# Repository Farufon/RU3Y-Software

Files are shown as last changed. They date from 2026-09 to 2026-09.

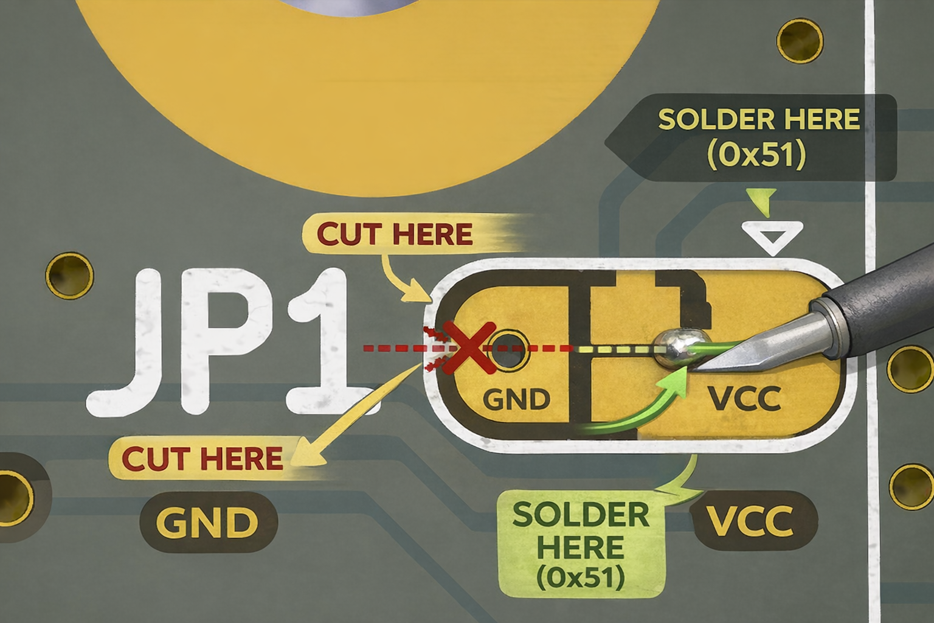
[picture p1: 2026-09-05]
TFRPM01/HOw address the boards.png

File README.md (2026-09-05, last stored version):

# Nacelle Thrust Stand

An axial-post thrust stand for measuring single-nacelle thrust, electrical power, and
ground-effect behaviour on a 914 mm-disc (R = 457 mm) VTOL tilt-rotor nacelle.

Built for a two-nacelle, 15 lb tilt-rotor VTOL. Hover thrust per nacelle is 7.5 lbf.
The deliverable this rig produces is a family of curves: **electrical watts required to
produce 7.5 lbf, as a function of rotor height above ground.**

---

## Start here

- Never used an Arduino? -> `docs/10-arduino-first-time.md`
- Already have the parts and want one page? -> `docs/00-quickstart.md`
- Want to try the software before parts arrive? -> `python3 tools/bench.py --simulate`
- **Before the first spin** -> `docs/09-safety.md`

## What is in this package

```
README.md                          this file

docs/00-quickstart.md              one page, if you already have the parts
docs/01-system-design.md           why this rig, what it measures, what it cannot
docs/02-bill-of-materials.md       parts, quantities, sources, links
docs/03-mechanical-build.md        step-by-step assembly
docs/04-wiring.md                  load cell to HX711 to Arduino, noise control
docs/05-calibration.md             load cell calibration, bidirectional, through-zero check
docs/05a-pitch-and-rpm-calibration.md
                                   servo->pitch and throttle->governed RPM. Do this first.
docs/06-test-protocol.md           the height / RPM / collective grid
docs/07-data-reduction.md          turning the raw log into the delivered curves
docs/08-post-vs-hinge.md           the argument, for the conversation with Vermont
docs/09-safety.md                  read before the first spin
docs/10-arduino-first-time.md      IDE setup, Uno vs Nano, drivers, upload errors
docs/11-load-cell-datasheet.md     ATO cell dimensions, specs, and CAD envelope
docs/wiring-adafruit-hx711.svg     printable wiring diagram - Adafruit 5974 board
docs/wiring-generic-hx711.svg      printable wiring diagram - SparkFun / generic green

firmware/thrust_stand/
    thrust_stand.ino               the sketch. tare, calibrate, stream.

tools/
    bench.py                       laptop app: menu, guided run capture, CSV logging
    reduce.py                      turns the run log into the deliverable table
    requirements.txt               pyserial, and nothing else

data/
    run-log-template.csv           the sheet, if you prefer filling it in by hand
```

## The software, in one paragraph

`thrust_stand.ino` runs on the Arduino and does one job: read the load cell and print
thrust over USB. `bench.py` runs on your laptop, drives the sketch, and walks you through
taring, calibration and a full collective staircase at a governed RPM, writing rows
    into a CSV as you go.
`reduce.py` reads that CSV and interpolates the watts required at 7.5 lbf for every height
you tested. That last table is what you send to Vermont.

## The short version

1. Build the post. Nacelle on top, S-beam load cell directly underneath it, post below
   that, three splayed legs reaching past the disc radius.
2. Wire the cell to an HX711 to an Arduino. Flash the sketch.
3. `pip3 install -r tools/requirements.txt`, then `python3 tools/bench.py`.
4. Calibrate once against known weights.
5. Per height: tare, run the staircase, log each plateau, tare again to verify.
6. `python3 tools/reduce.py data/runs.csv --thrust 7.5 --radius 457`

## Expect

267 to 295 W electrical per nacelle at 7.5 lbf, out of ground effect, depending on
head RPM. Predicted 280 W at 1800 rpm, which matches Austin's measured figure. Hover
collective
about 16 deg at 0.75R at 1600 rpm, falling to 10 deg at 2000. Ground effect will save real
power near the floor, but less than
the textbook thrust benefit suggests, because it reduces induced power only.

## Read first

`docs/09-safety.md`. A 914 mm disc at hover thrust holds enough energy to kill you if a
blade lets go. The blade-failure plane is a **disc, not a cone.** Do not stand in it.

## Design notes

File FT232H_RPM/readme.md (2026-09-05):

##  Pre-Run Hardware Setup

1. **Connections**

   * ESC white signal/tach (AUX) → **1 kΩ resistor** → FT232H **AD0 (D0)**
   * ESC GND → FT232H GND
   * Do **not** connect main PWM throttle line to FT232H (use only AUX/tach output).

2. **Power**

   * Motor/ESC powered by flight battery (watch props/rotor, secure heli or remove blades for bench test).
   * FT232H powered via USB to your Mac/PC.

3. **Safety**

   * Strap heli down or remove main/tail blades during first tests.
   * Wear eye protection — ESCs/motors can surge unexpectedly.

---

##  Software / Command Setup

1. Open Terminal:

   ```bash
   cd ~/Desktop/FT232H_RPM
   ```

2. Run test with **raw motor RPM only**:

   ```bash
   ./rpm_reader_static --poles 8 --ratio 1.0 --index 0 --window 0.05
   ```

   * `--poles 8` = Align 470MX motor (8 poles).
   * `--ratio 1.0` = just motor speed.
   * `--index 0` = first FT232H device.
   * `--window 0.05` = 50 ms averaging window.

3. Run with **gear ratio compensation (rotor head RPM)**:

   ```bash
   ./rpm_reader_static --poles 8 --ratio 8.0 --index 0 --window 0.05
   ```

---

##  Output Verification

Sample output:

```
# t_s, edges, edges_per_s, motor_rpm, rotor_rpm
0.050,120,2400.0,20571,2571
0.100,118,2360.0,20228,2529
```

* `edges` should scale with throttle smoothly.
* `motor_rpm` should be \~20k+ at full throttle (check motor Kv × voltage).
* `rotor_rpm` should be \~2.4–2.6k at 8:1 ratio (matches typical head speeds).

---

##  Sanity Checks

* **Idle / Low Throttle**: rotor\_rpm should rise linearly with throttle.
* **No Throttle**: output should show near zero (a few stray edges OK).
* **Full Throttle**: compare `motor_rpm ≈ Kv × Voltage` and ensure rotor\_rpm ≈ motor\_rpm ÷ ratio.

  * Example: 1800 Kv × 22.2 V ≈ 40k rpm (no load). With 8:1 gear, rotor ≈ 5k rpm max (likely lower under load).

---

 **Tip**: If you see motor RPM correct but rotor RPM looks wrong, double-check `--ratio`.
 If both look wrong, double-check `--poles`.

## LOG TO CSV

Good timing — your program already prints CSV-style lines to `stdout`. You can **tee** or **redirect** them so you get both: live on screen *and* saved to a CSV file.

---

###  Option 1: Tee to File

Keeps live output on screen *and* writes to file:

```bash
./rpm_reader_static --poles 8 --ratio 8.0 --index 0 --window 0.05 | tee rpm_log.csv
```

---

###  Option 2: Redirect to File (no live screen)

Writes only to file (silent on screen):

```bash
./rpm_reader_static --poles 8 --ratio 8.0 --index 0 --window 0.05 > rpm_log.csv
```

---

###  Option 3: Append (multiple runs into one file)

```bash
./rpm_reader_static --poles 8 --ratio 8.0 --index 0 --window 0.05 | tee -a rpm_log.csv
```

---

###  Notes

* The first line of the output (`# t_s, edges, edges_per_s, motor_rpm, rotor_rpm`) will serve as your CSV header.
* If you plan to import into Excel/Numbers, you may want to remove the `#` from the header afterward.

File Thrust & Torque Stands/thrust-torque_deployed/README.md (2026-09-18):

# Nacelle Thrust Stand

An axial-post thrust stand for measuring single-nacelle thrust, electrical power, and
ground-effect behaviour on a 914 mm-disc (R = 457 mm) VTOL tilt-rotor nacelle.

Built for a two-nacelle, 15 lb tilt-rotor VTOL. Hover thrust per nacelle is 7.5 lbf.
The deliverable this rig produces is a family of curves: **electrical watts required to
produce 7.5 lbf, as a function of rotor height above ground.**

Measured operating points from flight test, per nacelle: **hover 1800 rpm at 446 W**,
**cruise after transition 1000 rpm at 185 W**. Rotor disc R = 457 mm. The BEMT model in
this package predicts 274 W for hover and is therefore known to be about 1.6 low; the
torque stand (`docs/14-torque-stand.md`) is how the campaign finds out where that factor
lives.

---

## Start here

- Never used an Arduino? -> `docs/10-arduino-first-time.md`
- Already have the parts and want one page? -> `docs/00-quickstart.md`
- Want to try the software before parts arrive? -> `python3 tools/bench.py --simulate`
- **Python on the Mac: use a venv** -> `docs/15-python-venv.md`. Everything in `tools/`
  assumes you have activated it.
- **Updating, and killing a stale process** -> `INSTALL.md`. Read it before unpacking a new
  zip; Finder will quietly make a `... 2` folder and leave you running old code.
- Not sure which version is on disk? -> `cat VERSION` or `python3 tools/live.py --version`
- **Before the first spin** -> `docs/09-safety.md`

## Arduino and serial: the working configuration

Everything below is proven on the actual hardware. If the board will not flash or
will not talk, this is the section to read. Same text as
`docs/13-arduino-working-config.md`.

Elegoo Nano V3.0 (ATmega328P / CH340) on Intel Mac, macOS 15.7.5.

### The rule

**Use Arduino IDE 1.8.19. Do not use 2.3.10 for uploads.**

2.3.10 ships avrdude 8.0, which cannot write flash to this board.
1.8.19 ships avrdude 6.3, which writes it in 0.23 seconds.

### Settings

| Item | Value |
|---|---|
| IDE | Arduino 1.8.19 (the app named `Arduino`, not `Arduino IDE`) |
| Board | Tools > Board > Arduino AVR Boards > Arduino Nano |
| Processor | Tools > Processor > **ATmega328P** (NOT Old Bootloader) |
| Port | Tools > Port > `/dev/cu.usbserial-XXXX` |
| Verify after upload | Can stay on. Read-back verifies clean on the soldered board. |
| Serial Monitor baud | 115200 for `thrust_stand.ino`, line ending New Line |

Old Bootloader sets 57600 and fails to sync. Plain ATmega328P sets 115200 and works.

### Before every upload

- Quit Arduino IDE 2.3.10 if it is open. Only one program can hold the port.
- Close the Serial Monitor. It holds the port too.
- Nothing connected to D0 (RX) or D1 (TX).
- Re-check Tools > Port after any replug. The name changes.

### Good log looks like

```
avrdude: Version 6.3-20190619
avrdude: Device signature = 0x1e950f (probably m328p)
avrdude: writing flash (924 bytes):
Writing | ############################ | 100% 0.23s
avrdude: 924 bytes of flash written
```

If the version line says `8.0-arduino.1`, you are in the wrong IDE. Stop.

### Known cosmetic errors, safe to ignore

- `the selected serial port does not exist or your board is not connected`
  appended after a successful upload. 1.8.19 concatenating error strings.

### Talking to the board without the Arduino IDE

The firmware does not care what is on the other end of the wire. Any serial
terminal at 115200 baud that sends a newline on Return will work. macOS has
one built in.

#### Find the port

```
ls /dev/cu.usbserial-*
```

If that comes back empty, or you want to see everything:

```
ls /dev/cu.*
```

Ignore `cu.Bluetooth-Incoming-Port` and anything Bluetooth-related. The Nano
is the `cu.usbserial-` entry. If more than one shows up, unplug the Nano,
run it again, plug back in, run it again, and take the one that appeared.

Always use `cu.`, never `tty.`. The `tty.` device blocks waiting for carrier
detect and will hang.

#### Open it

```
screen /dev/cu.usbserial-1480 115200
```

Substitute the actual name from the `ls`. The board resets when the port
opens, so the banner prints a second or so later. Return sends a newline
already, so `t`, `c 3.11`, `d` and `r` all work as typed.

#### Quit

`Control-A` then `Control-\` then `y`. Or `Control-A` then `k` then `y`.

**Quit properly.** Closing the Terminal window leaves `screen` holding the
port and the next thing that tries to open it will fail. If that happens:

```
screen -ls
screen -X -S <the-session-name> quit
```

#### Logging to a file

`screen` scrollback is awkward. To capture a session:

```
screen -L -Logfile ~/thrust-run.txt /dev/cu.usbserial-1480 115200
```

#### Alternatives

- **CoolTerm** (free, GUI): scrollback, logging, timestamps. Easier than
  `screen` for long runs.
- **`tools/live.py`** is the best option in this branch: browser dashboard,
  strip chart, logging, BEMT overlay, and it works from an iPad over the VPN.
  See `docs/12-live-readout.md`.
- **`tools/bench.py`** is the guided grid-capture session. It drives the same port, prompts through the height / RPM /
  collective grid, and writes `data/run-log.csv` directly. No transcribing
  numbers by hand.

### Firmware command reference (`thrust_stand.ino`)

115200 baud, line ending **New Line**. Commands are single letters, case
insensitive, one per line. Anything unrecognised returns `! unknown command`.

| Cmd | Does | Output starts with |
|---|---|---|
| `h` | Help. `?` works too. | `=== Nacelle Thrust Stand ===` |
| `t` | **Tare.** Zeroes to current load, 32 samples. | `# taring, hold still...` |
| `r` | One reading, 8 samples averaged. | `# n,ms,lbf,N,raw` |
| `s` | Toggle streaming. Real rate is ~1.2 Hz on RATE=L. | `# streaming ON` / `OFF` |
| `c <lbf>` | **Calibrate** against a hung known weight, 32 samples. | `# calibrating against ...` |
| `f` | **Flip sign. Required on this rig, every calibration.** | `# sign now -1` |
| `z` | Raw counts, unscaled, 32 samples. Diagnostics. | `# raw counts = ` |
| `d` | Dump settings. | `calFactor (counts/lbf) :` |
| `w` | Force-write settings to EEPROM. | `# settings written` |

#### Reading format

```
# n,ms,lbf,N,raw
4,1106238,3.0906,13.748,444579
```

| Field | Meaning |
|---|---|
| `n` | Sample counter. Resets to 0 when streaming starts. |
| `ms` | `millis()` since boot. Not wall clock. |
| `lbf` | Change from tare, in pounds force. **Meaningless until calibrated.** |
| `N` | Same value in newtons (lbf x 4.4482216). |
| `raw` | Raw HX711 counts, 2 samples. Absolute, not tare-relative. |

`raw` is the field to trust before calibration and the field to watch for
drift after.

#### What survives a power cycle, and what does not

Stored in EEPROM: **calFactor** and **sign**. Both reload at boot.

**NOT stored: the tare offset.** `setup()` re-tares on every boot, 32 samples,
against whatever is sitting on the cell at that instant.

Consequences:

- Do not power up with a load hanging. The board will treat that load as zero.
- The boot banner tells you which state you are in. Either
  `# calibration loaded from EEPROM, calFactor = ...` or
  `# NO CALIBRATION STORED.`
- You still tare with `t` at the start of every run, per the protocol. The
  boot tare is not a substitute, the rig will not have settled yet.

#### Calibration sequence

1. Nacelle mounted, nothing else on it, rig settled. `t`
2. Stack the known weight on the nacelle mount. `c 15.0`
3. `d` and confirm calFactor is no longer `1.0000`.
4. `r` with the weight still on. Should read close to the known value.
5. Swap in a second known weight. `r`. Should read close to that one.
6. Remove all added weight. **`f`.**
7. `d`, confirm `sign : -1`. Lift the mount by hand, `r`, confirm **positive**.

**`f` is not optional on this stand.** The cell sits on top of the post with the
nacelle above it, so dead weight is compression and thrust is tension. `c`
always makes the calibration direction positive, so calibrating with weight
stacked on the mount makes compression positive and thrust would read negative.
Send `f` after every `c`. See `docs/05-calibration.md`.

Guards in the code: `c` with a non-positive number is rejected. `c` with less
than 1000 counts of signal is rejected as "signal too small", which means the
weight is not actually on the cell or the wiring is broken.

#### Per-run procedure

`t` motor off and settled, `s` to stream, run the collective staircase at a
governed RPM, `s` to stop, `t` again and check the zero. **If the second tare
has wandered, discard the run.**

### macOS Terminal command reference

| Command | Does |
|---|---|
| `ls /dev/cu.usbserial-*` | Find the Nano. |
| `ls /dev/cu.*` | List every serial device if the above is empty. |
| `screen /dev/cu.usbserial-1480 115200` | Open the connection. |
| `Control-A` then `Control-\` then `y` | Quit screen properly. |
| `Control-A` then `k` then `y` | Kill the window, same effect. |
| `Control-A` then `Control-A` | Send a literal Control-A to the board. |
| `screen -ls` | List sessions left running. |
| `screen -X -S <name> quit` | Kill an orphaned session holding the port. |
| `screen -L -Logfile ~/run.txt /dev/cu.usbserial-1480 115200` | Open and log to file. |
| `lsof /dev/cu.usbserial-1480` | Find what process is holding the port. |
| `system_profiler SPUSBDataType \| grep -A8 -i ch34` | Confirm the CH340 enumerated at all. |

`screen` does not echo what you type. You will see the board's replies but not
your own keystrokes. That is normal, not a dead connection.

### Cable length

USB 2.0 passive cable tops out at about 5 m (16 ft). Beyond that, expect
intermittent dropouts. For a long run to the stand use an **active** USB
extension (repeater chip in the connector) or a **mains-powered** hub at the
midpoint. A bus-powered hub on a long cable is worse than no hub.

A hub does not change the device identity. The CH340 keeps its vendor and
product ID and still enumerates as `cu.usbserial-`. Only the number changes,
same as it does on any replug.

Lengthen the USB, never the load cell leads. Those carry millivolt analog
signal and will pick up ESC and motor noise. Nano and HX711 stay at the stand.

### Do not

- Do not install the WCH CH34x driver. Current setup works. Leave it alone.
- Do not buy a USBasp. Bootloader is fine, signature reads clean.
- Do not use Old Bootloader.
- Do not use `/dev/tty.usbserial-*`. Use `/dev/cu.usbserial-*`.

---

## What is in this package

```
README.md                          this file

docs/00-quickstart.md              one page, if you already have the parts
docs/01-system-design.md           why this rig, what it measures, what it cannot
docs/02-bill-of-materials.md       parts, quantities, sources, links
docs/03-mechanical-build.md        step-by-step assembly
docs/04-wiring.md                  load cell to HX711 to Arduino, noise control
docs/05-calibration.md             load cell calibration, bidirectional, through-zero check
docs/05a-pitch-and-rpm-calibration.md
                                   servo->pitch and throttle->governed RPM. Do this first.
docs/06-test-protocol.md           the height / RPM / collective grid
docs/07-data-reduction.md          turning the raw log into the delivered curves
docs/08-post-vs-hinge.md           the argument, for the conversation with Vermont
docs/09-safety.md                  read before the first spin
docs/10-arduino-first-time.md      IDE setup, Uno vs Nano, upload errors, first bring-up
docs/11-load-cell-datasheet.md     ATO cell dimensions, specs, and CAD envelope
docs/12-live-readout.md            tools/live.py: browser dashboard, logging, power overlay
docs/13-arduino-working-config.md  THE PROVEN SETTINGS. Read this one first if stuck.
docs/14-torque-stand.md            the separate torque rig: second board, second cell
docs/15-python-venv.md             Python on the Mac. Do this before any tools/ command.
docs/wiring-adafruit-hx711.svg     printable wiring diagram - Adafruit 5974 board
docs/wiring-generic-hx711.svg      printable wiring diagram - SparkFun / generic green
docs/wiring-torque-stand.svg       torque stand wiring - second Nano, second HX711, 5 kg cell
docs/torque-stand-elevation.svg    torque stand side elevation with callouts
docs/torque-stand-plan.svg         torque stand plan view: arm, cell, anchor, calibration notes

firmware/thrust_stand/
    thrust_stand.ino               the sketch. tare, calibrate, stream.

firmware/torque_stand/
    torque_stand.ino               second board. reports torque in N.m. See docs/14.

cad/
    torque_cradle.py               Fusion script, builds the torque cradle parts

INSTALL.md                         unpacking, updating, killing stale processes. READ FIRST.
VERSION                            date-stamped build id; live.py prints it at startup

tools/
    stop.sh                        kills stale live.py/bench.py, reports port holders
    live.py                        browser dashboard: live readout, strip chart,
                                   logging, BEMT power overlay. See docs/12.
    bemt_curves_v49.json           predicted thrust/power curves, R = 457 mm
    bench.py                       laptop app: menu, guided run capture, CSV logging
    reduce.py                      turns the run log into the deliverable table
    requirements.txt               pyserial, and nothing else. Install into a venv,
                                   never the system Python. See docs/15.

data/
    run-log-template.csv           the sheet, if you prefer filling it in by hand
```

## The software, in one paragraph

`thrust_stand.ino` runs on the Arduino and does one job: read the load cell and print
thrust over USB. `bench.py` runs on your laptop, drives the sketch, and walks you through
taring, calibration and a full collective staircase at a governed RPM, writing rows
    into a CSV as you go.
`reduce.py` reads that CSV and interpolates the watts required at 7.5 lbf for every height
you tested. That last table is what you send to Vermont.

## The short version

1. Build the post. Nacelle **bolted** on top, S-beam load cell **bolted** directly
   underneath it, post below that, three splayed legs reaching past the disc radius.
   Both studs carry load: dead weight presses the cell in compression, thrust pulls it in
   tension, and it reads continuously through zero between them.
2. Wire the cell to an HX711 to an Arduino. Flash the sketch (IDE 1.8.19, plain ATmega328P).
3. Set up the Python environment once, per `docs/15-python-venv.md`:

```
/Library/Frameworks/Python.framework/Versions/3.12/bin/python3 -m venv ~/venvs/forcerigs
xattr -r -d com.apple.quarantine ~/venvs/forcerigs/
source ~/venvs/forcerigs/bin/activate
pip install --upgrade pip
pip3 install pyserial
```

Every new Terminal window needs the `source` line again. The prompt shows
`(forcerigs)` when it is live. Full detail, including how to start over, is in
`docs/15-python-venv.md`.

   Then `cd tools && python3 bench.py`.
4. Calibrate once, in compression, with weight stacked on the nacelle mount. **Then send
   `f`.** It is required on this geometry, and any recalibration undoes it, so `f` goes last
   every time. Confirm `sign : -1` and that lifting the mount reads positive.
5. Per height: tare with the nacelle on and the motor off, run the staircase, log each
   plateau, tare again to verify.
6. `python3 tools/reduce.py data/runs.csv --thrust 7.5 --radius 457`

## Expect

The BEMT predicts 267 to 295 W electrical per nacelle at 7.5 lbf out of ground effect,
depending on head RPM, with hover collective about 16 deg at 0.75R at 1600 rpm falling to
10 deg at 2000.

**Flight test puts hover at 446 W per nacelle at 1800 rpm**, against a prediction of
274 W. Your 1800 rpm OGE point must land near 446 before anything else means anything. That is a factor of 1.63, and it implies a figure of merit of 0.43 where the model
claims 0.70. Either the rotor is far worse than modelled, or the drivetrain is running at
about 48% rather than the assumed 79%. Electrical watts alone cannot separate those two.
The torque stand can, and that is what `docs/14-torque-stand.md` is for.

The `live.py` power chart marks that point with an amber diamond. Expect your captured
points to land near it and well above the BEMT curves. The gap to the curves is the
model's problem; the gap to the diamond is yours.

His cruise target after transition is 1000 rpm at 185 W per nacelle. That point is not
reproducible on a static stand; see doc 14.

Ground effect will save real power near the floor, but less than the textbook thrust
benefit suggests, because it reduces induced power only.

## Read first

`docs/09-safety.md`. A 914 mm disc at hover thrust holds enough energy to kill you if a
blade lets go. The blade-failure plane is a **disc, not a cone.** Do not stand in it.

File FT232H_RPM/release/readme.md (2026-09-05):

Great—thanks for the exact filenames. You have:

* `build/libftd2xx.1.4.30.dylib` (dynamic library)
* `build/libftd2xx.a` (static library)
* `ftd2xx.h`, `WinTypes.h`
* plus some subfolders

Below is a **from-scratch, copy-pasteable** setup that works with *your* files and avoids guessing.

---

# 1) Make a clean project folder

```bash
mkdir -p ~/Desktop/FT232H_RPM
cd ~/Desktop/FT232H_RPM
```

Copy the **headers** and the **.dylib** in:

```bash
# adjust the source path below to wherever your "release" folder actually is:
cp /Users/jon/Desktop/FT232H_RPM/release/ftd2xx.h .
cp /Users/jon/Desktop/FT232H_RPM/release/WinTypes.h .
cp /Users/jon/Desktop/FT232H_RPM/release/build/libftd2xx.1.4.30.dylib .
```

(Optional but convenient) add a symlink with a generic name:

```bash
ln -sf libftd2xx.1.4.30.dylib libftd2xx.dylib
```

You should now have:

```
~/Desktop/FT232H_RPM/
  ftd2xx.h
  WinTypes.h
  libftd2xx.1.4.30.dylib
  libftd2xx.dylib  -> libftd2xx.1.4.30.dylib (symlink)
```

---

# 2) Check architecture (VERY IMPORTANT on Apple Silicon)

Your Mac is **arm64**. Make sure the library matches:

```bash
lipo -info libftd2xx.1.4.30.dylib
```

* If it says **arm64** (or **arm64 x86\_64**), you’re good.
* If it says **x86\_64 only**, you have an Intel-only build. Either:

  * grab an **arm64** macOS D2XX build, **or**
  * run under Rosetta (see “Plan B” at the end).

---

# 3) Create the app source file

Create `rpm_reader.c` here with this content (same as earlier, kept local-include):

```c
// rpm_reader.c — FT232H + D2XX RPM reader for Castle ESC AUX "RPM OUT"
// Wiring: ESC white AUX -> 1k -> FT232H AD0 (D0); ESC GND -> FT232H GND
// Build:  clang -O2 -Wall rpm_reader.c -o rpm_reader -I. -L. -l:libftd2xx.1.4.30.dylib -Wl,-rpath,@executable_path

#include <stdio.h>
#include <stdlib.h>
#include <stdint.h>
#include <string.h>
#include <time.h>
#ifdef __APPLE__
#include <mach/mach_time.h>
#endif

#include "ftd2xx.h"   // in current directory

static int    motor_poles = 14;     // total magnets, e.g. 14 -> 7 pole-pairs
static double gear_ratio  = 1.0;    // motor:rotor (10.0 for 10:1)
static int    dev_index   = 0;      // FTDI device index to open
static double window_s    = 0.05;   // seconds per RPM sample (50 ms)

static double now_s(void) {
#ifdef __APPLE__
    static mach_timebase_info_data_t tb;
    static uint64_t start = 0;
    if (!tb.denom) mach_timebase_info(&tb);
    if (!start) start = mach_absolute_time();
    uint64_t t = mach_absolute_time() - start;
    double ns = (double)t * (double)tb.numer / (double)tb.denom;
    return ns * 1e-9;
#else
    struct timespec ts; clock_gettime(CLOCK_MONOTONIC, &ts);
    return (double)ts.tv_sec + (double)ts.tv_nsec * 1e-9;
#endif
}

static void die(const char *msg, FT_STATUS st) {
    fprintf(stderr, "%s (FT_STATUS=%ld)\n", msg, (long)st);
    exit(1);
}

static void usage(const char *prog) {
    fprintf(stderr,
        "Usage: %s [--poles N] [--ratio R] [--index I] [--window S]\n"
        "  --poles   Total motor poles (default 14)\n"
        "  --ratio   Gear ratio motor:rotor (default 1.0)\n"
        "  --index   FTDI device index to open (default 0)\n"
        "  --window  Seconds per RPM sample window (default 0.05)\n",
        prog);
}

int main(int argc, char **argv) {
    for (int i=1; i<argc; ++i) {
        if (!strcmp(argv[i], "--poles") && i+1<argc)      motor_poles = atoi(argv[++i]);
        else if (!strcmp(argv[i], "--ratio") && i+1<argc) gear_ratio  = atof(argv[++i]);
        else if (!strcmp(argv[i], "--index") && i+1<argc) dev_index   = atoi(argv[++i]);
        else if (!strcmp(argv[i], "--window") && i+1<argc)window_s    = atof(argv[++i]);
        else { usage(argv[0]); return 1; }
    }
    if (motor_poles < 2) motor_poles = 2;
    int pole_pairs = motor_poles / 2;
    if (pole_pairs < 1) pole_pairs = 1;
    if (gear_ratio <= 0.0) gear_ratio = 1.0;
    if (window_s < 0.01) window_s = 0.01;

    FT_STATUS st;
    FT_HANDLE ft;

    st = FT_Open(dev_index, &ft);
    if (st != FT_OK) die("FT_Open failed", st);

    FT_SetLatencyTimer(ft, 2); // ms

    UCHAR mask = 0x00; // all inputs
    UCHAR mode = 0x01; // async bit-bang
    st = FT_SetBitMode(ft, mask, mode);
    if (st != FT_OK) die("FT_SetBitMode failed", st);

    printf("# t_s, edges, edges_per_s, motor_rpm, rotor_rpm\n");
    double t0 = now_s();
    double block_start = t0;

    UCHAR prev = 0, cur = 0;
    st = FT_GetBitMode(ft, &prev);
    if (st != FT_OK) die("FT_GetBitMode (init) failed", st);
    prev &= 0x01;

    for (;;) {
        unsigned edges = 0;
        double deadline = block_start + window_s;

        while (now_s() < deadline) {
            st = FT_GetBitMode(ft, &cur);
            if (st != FT_OK) die("FT_GetBitMode failed", st);
            UCHAR bit = cur & 0x01;  // AD0 is LSB
            if (prev == 0 && bit == 1) edges++; // rising edge
            prev = bit;
        }

        double window_actual = now_s() - block_start;
        block_start = now_s();

        double eps = edges / (window_actual > 0 ? window_actual : window_s);
        double motor_rpm = (eps * 60.0) / pole_pairs;
        double rotor_rpm = motor_rpm / gear_ratio;

        printf("%.3f,%u,%.1f,%.0f,%.0f\n",
               now_s()-t0, edges, eps, motor_rpm, rotor_rpm);
        fflush(stdout);
    }

    FT_Close(ft);
    return 0;
}
```

---

# 4) Build (links to your exact dylib name)

```bash
cd ~/Desktop/FT232H_RPM
clang -O2 -Wall rpm_reader.c -o rpm_reader \
  -I. -L. \
  -l:libftd2xx.1.4.30.dylib \
  -Wl,-rpath,@executable_path
```

**Why this works:**

* `-I.` and `-L.`: use headers and libs from the current folder
* `-l:…` links **that exact filename** (no need to rename)
* `-Wl,-rpath,@executable_path` lets the app find the dylib **next to the binary** at runtime

> If Gatekeeper blocks the library the first time, clear quarantine once:
>
> ```bash
> xattr -dr com.apple.quarantine libftd2xx.1.4.30.dylib rpm_reader
> ```

---

# 5) Wire & run

**Wiring recap**

* ESC **white AUX** → **1 kΩ** → FT232H **AD0 (D0)**
* ESC **GND** → FT232H **GND**
* Don’t connect the ESC +5 V to FT232H VCC (FT232H is USB powered)

**Run**

```bash
./rpm_reader --poles 14 --ratio 1.0 --index 0 --window 0.05
```

You should see CSV rows like:

```
# t_s, edges, edges_per_s, motor_rpm, rotor_rpm
0.051,125,2482.5,21236,21236
0.102,121,2410.3,20659,20659
```

Tweak flags as needed:

* `--poles N` → total motor poles (14 ⇒ 7 pole-pairs)
* `--ratio R` → motor\:rotor (10.0 for 10:1)
* `--window S` → 0.02–0.10 typical
* `--index I` → if multiple FTDI devices connected

---

## If you get errors

* **`ld: library not found for -l:libftd2xx.1.4.30.dylib`**
  Ensure the file is in the same directory as you’re compiling from and you included `-L.`

* **`dyld: Library not loaded: libftd2xx.1.4.30.dylib`**
  Ensure `-Wl,-rpath,@executable_path` is in the compile line, or run once with:

  ```bash
  export DYLD_LIBRARY_PATH=.
  ./rpm_reader ...
  ```

* **`image not found` or Apple security prompt**
  Clear quarantine:

  ```bash
  xattr -dr com.apple.quarantine libftd2xx.1.4.30.dylib rpm_reader
  ```

  If it still complains, open **System Settings → Privacy & Security** and click **Allow Anyway** for the blocked item, then run again.

* **Architecture mismatch**
  If `lipo -info` showed **x86\_64 only** and your Mac is arm64:

  * Best: obtain an **arm64** build of `libftd2xx.1.4.30.dylib`.
  * Plan B (Rosetta): build and run everything as x86\_64:

    ```bash
    # compile for x86_64
    arch -x86_64 clang -O2 -Wall rpm_reader.c -o rpm_reader_x86 \
      -I. -L. -l:libftd2xx.1.4.30.dylib -Wl,-rpath,@executable_path
    # run under Rosetta
    arch -x86_64 ./rpm_reader_x86 --poles 14 --ratio 1.0
    ```

* **Always zero edges**
  Check wiring (AD0/D0 is bit 0), **common ground**, and confirm **AUX = RPM Out** in Castle Link.

---

## Optional: static link (no .dylib at runtime)

If you want to avoid the dynamic library entirely and the static **`.a`** matches your architecture, you can link it directly:

```bash
clang -O2 -Wall rpm_reader.c -o rpm_reader_static \
  -I. /path/to/release/build/libftd2xx.a
```

If that works, you can run `./rpm_reader_static` without shipping a `.dylib`.

---

That’s the whole path with your specific `libftd2xx.1.4.30.dylib`. If you hit a specific compiler or runtime message, paste it verbatim and I’ll adjust the exact flags fast.

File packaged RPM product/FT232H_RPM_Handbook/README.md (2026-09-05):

# FT232H → Castle ESC RPM Kit (macOS, No Python)

This is a distributable handbook + project that measures **real‑time RPM** from a Castle ESC’s **AUX (white) RPM OUT** using an **FT232H** and the **FTDI D2XX** API—compiled as a **static binary** for a zero‑dependency run.

## Contents

```
FT232H_RPM_Handbook/
├─ src/
│  ├─ rpm_reader.c          # core reader (CSV to stdout)
│  └─ list_ftdi.c           # helper: list FTDI devices / serials
├─ docs/
│  ├─ C - FT232H TUTORIAL.md                 # full setup & wiring
│  ├─ QUICKSTART.md                          # concise run + logging
│  └─ RUNNING TWO RPM FT232Hs in REAL TIME.md# dual boards, AppleScript/tmux tips
├─ vendor/ftdi/
│  ├─ ftd2xx.h, WinTypes.h                   # FTDI headers
│  ├─ libftd2xx.a                            # static lib (preferred)
│  ├─ ftd2xx.cfg                             # optional config (advanced)
│  ├─ release-notes.txt                      # FTDI D2XX changelog
│  └─ ReadMe.rtf                             # FTDI install notes
├─ scripts/
│  ├─ build_static.sh                        # one-click static build
│  └─ run_dual.scpt                          # opens two Terminal windows
└─ BUILD.md                                   # build & run instructions
```

## Quick Start

1. **Props off.** Wire AUX (white) → 1 kΩ → FT232H **AD0(D0)** and **GND → GND**.  
2. Ensure Castle **AUX = RPM OUT** (Castle Link).  
3. Build static binary:

   ```bash
   ./scripts/build_static.sh
   ```

4. Run (single board):

   ```bash
   ./rpm_reader_static --poles 8 --ratio 8.0 --index 0 --window 0.05
   ```

   Log to CSV while keeping live output:

   ```bash
   ./rpm_reader_static --poles 8 --ratio 8.0 --index 0 --window 0.05 | tee rpm_log.csv
   ```

5. Run **two** FT232H boards (two windows):

   ```bash
   osascript scripts/run_dual.scpt
   ```

## Notes

- `motor_rpm` is derived from commutation edges and **pole‑pairs**.  
- `rotor_rpm = motor_rpm / gear_ratio`.  
- If you swap USB ports and device indices change, compile and use `src/list_ftdi.c` to enumerate serials and extend the reader to open by serial (optional).

---

**License & Attribution**  
FTDI headers/libraries are © FTDI and redistributed under their terms. See `vendor/ftdi/release-notes.txt` and the header notices. Your source files are yours—add your preferred license as needed.

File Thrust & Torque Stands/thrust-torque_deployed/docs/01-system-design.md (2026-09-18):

# 01 - System Design

## The question this rig answers

Vermont has flying aircraft. The question is not "will it lift." The question is what the
power draw looks like through the takeoff transition, from sitting on the ground up to
free-air hover, where ground effect is real and where the pack sees its hardest moment.

So the measured output is:

> **Electrical watts to produce 7.5 lbf, as a function of rotor height above ground,
> minimised over the available combinations of head RPM and collective pitch.**

Not thrust at full throttle. Not thrust at one height. A curve of watts against height at
constant thrust. That is what sizes his pack and tells him what climb-out costs.

## Rotor definition - settled

This was ambiguous for a while and is now closed. From Austin's design source, 4 September:

```
tip_radius          = 457.0    // tip radius from hub centerline, mm
CENTER_HUB_to_FIBER =  31.0    // hub centreline to base of the grip
```

**457 mm is the rotor radius, measured from the hub centreline to the blade tip.** The blade
itself is 426 mm of physical length, running from r = 31 mm out to r = 457 mm.

The earlier `BLADETEST.step` file, 499.5 mm root face to tip, is **superseded**. Austin
identified it as one of an earlier family built while he was exploring longer radii. Do not
size anything from it. The current blade is the **SOLID CORE V49** pair, supplied as
`PROP_CORE_CW` and `PROP_CORE_CCW`.

### Measured blade geometry, V49 core

Taken directly off the supplied STL meshes rather than from the design intent.

| Quantity | Value |
|---|---|
| Rotor radius R | 457.0 mm |
| Blade physical length | 426.0 mm (r = 31 to 457) |
| Blades per rotor | 2 |
| Max chord | 33.84 mm at r/R = 0.75 |
| Reference chord (Austin's source) | 35.0 mm |
| Built-in twist, r/R 0.22 to tip | 33.3 degrees, washout |
| Thickness ratio | 17.7% at r/R 0.22, tapering to 12.2% at the tip |
| Geometric solidity | 0.0286 |
| Thrust-weighted solidity | 0.0388 |
| Thrust-weighted equivalent chord | 27.8 mm |
| Disc area | 0.656 m^2 |
| Disc loading at 7.5 lbf | 50.8 N/m^2 |
| Root airfoil | GOE 601 |
| Tip airfoil | DEFIANT CANARD |

The CW and CCW files were checked against each other and are an **exact mirror pair**, zero
deviation after reflection. The handed set is correct; you are not about to build two rotors
of the same hand.

Note these are the **printed cores**. The finished blade carries carbon over them, two to
five plies per side depending on span station, which adds a little thickness and a little
chord. The aerodynamic effect is small and is inside the uncertainty of the drag polar.

## Measured operating points

These come from Austin's per-blade and flying tests and are the numbers the rig has to
reproduce. Both are **per nacelle**. Rotor disc unchanged, R = 457 mm.

| Condition | Head RPM | Electrical W | A at 21 V | Shaft W at η 0.79 | Torque |
|---|---|---|---|---|---|
| **Hover** | **1800** | **446** | 21.2 | 352 | 1.87 N·m |
| **Cruise**, after transition | **1000** | **185** | 8.8 | 146 | 1.39 N·m |

The shaft column assumes the nominal 0.95 x 0.83 drivetrain until the torque stand
replaces that assumption with a measurement. The torque column is what the torque stand
should read at each condition if the assumption holds.

Aircraft totals, two nacelles: 892 W in hover, 370 W in cruise.

## Predicted power at hover, BEMT

Blade-element momentum analysis against the measured V49 geometry, tip-loss corrected,
trimmed to 7.5 lbf per nacelle, with 0.95 gearbox and 0.83 combined motor and ESC
efficiency. **This is the model. It is now known to be wrong by a factor of about 1.6 at
the hover point, and the interesting question is where that factor lives.**

| Head RPM | Tip speed m/s | Collective at 0.75R | Shaft W | FM | Electrical W | A at 21 V | Max thrust lbf | Margin |
|---|---|---|---|---|---|---|---|---|
| 1500 | 71.8 | 20.5 | 228 | 0.666 | 290 | 13.8 | 7.5 | **1.00** |
| 1600 | 76.6 | 16.1 | 217 | 0.699 | 276 | 13.1 | 8.6 | 1.14 |
| 1700 | 81.4 | 14.1 | 218 | 0.698 | 276 | 13.2 | 9.7 | 1.29 |
| **1800** | 86.1 | 12.6 | 221 | 0.688 | **280** | 13.3 | 10.8 | 1.44 |
| 1900 | 90.9 | 11.3 | 226 | 0.673 | 286 | 13.6 | 12.1 | 1.61 |
| 2000 | 95.7 | 10.3 | 232 | 0.655 | 294 | 14.0 | 13.4 | 1.78 |

At 1400 rpm this rotor **cannot reach 7.5 lbf at all** before the blade stalls.

Two things to take from this table, and one retraction.

**The model is out by about 1.6 at hover.** It predicts 274 to 280 W at 1800 rpm depending
on the drag polar (the table above is one run, the curve file in `tools/` is another);
Austin measures 446 W.
At the assumed drivetrain efficiency that is 352 W of shaft power for a job whose ideal
induced power is 152 W, a figure of merit of 0.43 where the model claims 0.69. Two
explanations fit and are not distinguishable from electrical watts alone:

- the rotor is far worse than modelled and really does take about 352 W of shaft power, or
- the rotor is close to the model at about 216 W and the drivetrain is delivering roughly
  48 percent rather than 79.

Any mix of the two is also possible. Separating them is exactly what `docs/14-torque-stand.md`
exists for, and it decides whether the fix is in the blades or in the motor and ESC. Until
that measurement exists, treat every BEMT number in this package as a shape, not a value.

**Power is nearly flat with RPM in the model; thrust margin is not.** Between 1600 and 2000
rpm predicted hover power varies by under 7 percent, but maximum thrust nearly doubles, from
8.6 to 13.4 lbf. RPM on this rotor buys control authority far more than it costs
efficiency. That conclusion is about the shape of the curves and should survive the 1.6
factor; the sweep will confirm or kill it.

> **Retraction, September 2026.** An earlier version of this document said the 280 W
> figure was **confirmed**, because the model landed on Austin's then-measured 280 W at
> 1800 rpm. Flying tests now put hover at 446 W. The agreement was a coincidence and I
> over-read it. What changed between the 280 W reading and the 446 W reading is a question
> for Austin, but the 446 W figure is the one from flight and it stands.

> **Retraction, earlier.** Working from the superseded 499.5 mm blade with its 46.3 degree
> twist, I recommended exploring **lower** head RPM on the grounds that 1600 was above the
> figure-of-merit optimum. That does not survive the corrected geometry. On the V49 the FM
> peak sits near 1600 to 1700 rpm and is very flat, while thrust margin falls away steeply
> below it. The sweep in doc 06 runs upward from 1600.

### The governor question is closed: 1800

Earlier in this project the nacelle RPM was quoted as 1600 and Austin's design source said
1800. Flying tests settle it: **hover is at 1800 rpm.** The 1600 row in the table above
is still worth measuring, because it shows how much margin the aircraft would give up by
slowing down, but it is not the operating point.

### Cruise is not a static condition

After transition the nacelles tilt and the rotor works as a propeller with axial inflow
from airspeed. At 1000 rpm and 185 W it is absorbing 1.39 N·m. Statically at 1000 rpm the
model tops out at 3.34 lbf, 88 W and 0.66 N·m at 21.9 degrees collective, so a static
stand runs out of collective at about half the cruise torque. The thrust stand cannot
reproduce cruise, and the deliverable does not ask it to. What transfers from cruise is
the drivetrain efficiency at 1000 rpm and 1.39 N·m, which the torque stand can get by
loading the motor in deep stall if the head has the pitch range. Doc 14 covers it.

## Ground effect, and why the height ladder matters

The classic Cheeseman-Bennett relation gives the thrust benefit at constant power:

```
T_IGE / T_OGE  =  1 / (1 - (R / 4z)^2)
```

where `z` is rotor height above ground and `R` is rotor radius. At R = 457 mm:

| z/R | z (mm) | z (in) | T_IGE / T_OGE |
|---|---|---|---|
| 0.5 | 229 | 9.0 | 1.333 |
| 0.75 | 343 | 13.5 | 1.125 |
| 1.0 | 457 | 18.0 | 1.067 |
| 1.25 | 571 | 22.5 | 1.042 |
| 1.5 | 686 | 27.0 | 1.029 |
| 2.0 | 914 | 36.0 | 1.016 |

**The model breaks down below z/R = 0.5.** At z/R = 0.33 the formula returns a 2.35x thrust
benefit, which is physically nonsense. Below half a radius, measure and do not predict. This
is one of the reasons the rig exists.

Two things follow:

1. Ground effect is essentially gone by z/R = 2. The residual benefit there is 1.6 percent,
   which is smaller than your measurement scatter. **The ladder therefore stops at z/R = 2**
   rather than running out to 3. At R = 457 that caps the top of the sweep at 914 mm, which
   is what makes indoor testing practical.
2. **Read the data at constant thrust, not constant power.** The table above is a thrust
   benefit. Vermont does not care that thrust rises near the ground. He cares that at his
   hover thrust the wattage is lower near the ground and climbs as the aircraft leaves it.

A caution on interpretation: ground effect reduces **induced** power only. Profile power
and drivetrain loss are unchanged by height. Ideal induced power at 7.5 lbf on this disc
is 152 W. The model put shaft power at about 220 W, making induced power **79 percent** of
the total; at the measured 446 W electrical and roughly 352 W shaft, induced power is only
about **43 percent** of the total, and the rest is profile drag, drivetrain loss, or both.
So a 7 percent thrust benefit near the floor buys well under 7 percent off the watts, and
less than the model would have led you to expect. Ground effect will still show clearly in
the data, but the low rungs of the ladder will save fewer watts than the textbook table
implies. Measure it rather than scaling it.

## Why the rotor is now governed, and what that does to the test

The head is **variable pitch with a governed RPM**. The ESC reads RPM and Austin's software
holds it at a setpoint. This changes the shape of the test fundamentally:

> **Throttle percentage is an RPM setpoint, not a power setting.** Thrust comes from
> collective pitch, not from throttle.

The original throttle staircase in this package measured nothing useful under a governor;
walking throttle up simply commanded a series of RPMs while the governor absorbed the
difference. The inner loop is now a **two-dimensional grid of head RPM against collective
pitch**, and the deliverable at each height is the (RPM, pitch) pair that produces 7.5 lbf
for the fewest watts. See doc 06.

## Build the rig parametric

Austin has said plainly that the radius **will increase later**, and that he will want
deeper gear ratios as props grow. Two consequences for the build:

- Splay the legs so the feet clear a **700 mm radius** rotor, not a 457 mm one. Recutting
  legs later is annoying; cutting them long now is free.
- Express the height ladder as **z/R with a fill-in millimetre column**, not as hard-coded
  millimetres. `reduce.py` takes `--radius` for exactly this reason.
- Plan floor-to-ceiling clearance for **4.2 m** so the same room still works at a larger
  radius. At R = 457 you need far less, but you do not want to move rooms.

Post sections get recut per prop. That is expected and cheap.

## Why an axial post

The nacelle mounts on top of a single vertical post that runs down the thrust axis,
directly beneath the hub. The prop sits above the motor in hover attitude, so the entire
volume below the nacelle is clear and the post never approaches the blades.

- **No lever arm.** Load is purely axial. There is no arm ratio to measure and therefore no
  arm ratio to get wrong.
- **Height is an independent variable.** You pin it and walk away. Nothing swings.
- **Almost nothing in the flow is measured.** The load cell sits directly under the nacelle.
  It only registers what is between it and the nacelle. The post, legs and base are below
  the cell and outside the load path, so their drag does not appear in the reading.

For scale on that last point: induced velocity at the disc is about 4.5 m/s at hover, rising
to roughly 9 m/s in the contracted wake. A 25 mm tube running two feet down through that
would carry roughly a tenth of a pound of download. Below the cell, it is exactly zero.

## The load reversal - read this before you build

The nacelle is about 1200 g. With the yoke and adapter plate the dead weight above the cell
is roughly **4.5 to 5 lb, acting downward in compression**. Thrust acts upward. So as you
walk the collective up, the cell passes through **zero net load at about 4.8 lbf of thrust**,
which is 64 percent of hover and sits in the middle of every sweep you will run.

This is not a nuisance detail. It has three consequences that are handled elsewhere in the
package and are listed here so the reason is in one place:

1. Any clearance in the threaded joints shows up as a **discontinuity right in the middle of
   the data**, and it looks convincingly like real aerodynamics. This is why the jam-nut
   preload and the no-rod-ends rule in doc 03 are load-bearing requirements rather than good
   practice.
2. The cell must be calibrated in **both directions**, and continuity through zero verified.
   See doc 05.
3. The hold-down must resist roughly **8 lbf of uplift** at peak thrust.

An optional 10 lb ballast above the cell keeps it in compression throughout, but it lowers
the fixture's resonant frequency toward 2/rev, which at 1800 rpm is 60 Hz. Try preload
first.

## What this rig cannot tell you

State these plainly in the delivery note.

1. **Fountain flow.** Two rotors on a wing, in ground effect, throw wake inward and upward
   against the underside of the wing. That download exists on the real aircraft and cannot
   appear in single-nacelle data.
2. **Rotor-to-rotor interference.** Same reason.
3. **Wing download in free-air hover.** The wing sits in the wake. Not reproduced here.
4. **Trim and control margin.** This measures thrust available, not authority remaining.

What you are delivering is **isolated per-nacelle performance, in and out of ground effect,
as a function of height, at the best available RPM and pitch combination.** Airframe
integration is Vermont's problem, and saying so up front protects both of you.

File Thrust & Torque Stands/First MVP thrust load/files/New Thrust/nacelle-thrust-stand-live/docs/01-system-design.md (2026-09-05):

# 01 - System Design

## The question this rig answers

Vermont has flying aircraft. The question is not "will it lift." The question is what the
power draw looks like through the takeoff transition, from sitting on the ground up to
free-air hover, where ground effect is real and where the pack sees its hardest moment.

So the measured output is:

> **Electrical watts to produce 7.5 lbf, as a function of rotor height above ground,
> minimised over the available combinations of head RPM and collective pitch.**

Not thrust at full throttle. Not thrust at one height. A curve of watts against height at
constant thrust. That is what sizes his pack and tells him what climb-out costs.

## Rotor definition - settled

This was ambiguous for a while and is now closed. From Austin's design source, 4 September:

```
tip_radius          = 457.0    // tip radius from hub centerline, mm
CENTER_HUB_to_FIBER =  31.0    // hub centreline to base of the grip
```

**457 mm is the rotor radius, measured from the hub centreline to the blade tip.** The blade
itself is 426 mm of physical length, running from r = 31 mm out to r = 457 mm.

The earlier `BLADETEST.step` file, 499.5 mm root face to tip, is **superseded**. Austin
identified it as one of an earlier family built while he was exploring longer radii. Do not
size anything from it. The current blade is the **SOLID CORE V49** pair, supplied as
`PROP_CORE_CW` and `PROP_CORE_CCW`.

### Measured blade geometry, V49 core

Taken directly off the supplied STL meshes rather than from the design intent.

| Quantity | Value |
|---|---|
| Rotor radius R | 457.0 mm |
| Blade physical length | 426.0 mm (r = 31 to 457) |
| Blades per rotor | 2 |
| Max chord | 33.84 mm at r/R = 0.75 |
| Reference chord (Austin's source) | 35.0 mm |
| Built-in twist, r/R 0.22 to tip | 33.3 degrees, washout |
| Thickness ratio | 17.7% at r/R 0.22, tapering to 12.2% at the tip |
| Geometric solidity | 0.0286 |
| Thrust-weighted solidity | 0.0388 |
| Thrust-weighted equivalent chord | 27.8 mm |
| Disc area | 0.656 m^2 |
| Disc loading at 7.5 lbf | 50.8 N/m^2 |
| Root airfoil | GOE 601 |
| Tip airfoil | DEFIANT CANARD |

The CW and CCW files were checked against each other and are an **exact mirror pair**, zero
deviation after reflection. The handed set is correct; you are not about to build two rotors
of the same hand.

Note these are the **printed cores**. The finished blade carries carbon over them, two to
five plies per side depending on span station, which adds a little thickness and a little
chord. The aerodynamic effect is small and is inside the uncertainty of the drag polar.

## Expected power at hover

Blade-element momentum analysis against the measured V49 geometry, tip-loss corrected,
trimmed to 7.5 lbf per nacelle, with 0.95 gearbox and 0.83 combined motor and ESC
efficiency.

| Head RPM | Tip speed m/s | Collective at 0.75R | Shaft W | FM | Electrical W | A at 21 V | Max thrust lbf | Margin |
|---|---|---|---|---|---|---|---|---|
| 1500 | 71.8 | 20.5 | 228 | 0.666 | 290 | 13.8 | 7.5 | **1.00** |
| 1600 | 76.6 | 16.1 | 217 | 0.699 | 276 | 13.1 | 8.6 | 1.14 |
| 1700 | 81.4 | 14.1 | 218 | 0.698 | 276 | 13.2 | 9.7 | 1.29 |
| **1800** | 86.1 | 12.6 | 221 | 0.688 | **280** | 13.3 | 10.8 | 1.44 |
| 1900 | 90.9 | 11.3 | 226 | 0.673 | 286 | 13.6 | 12.1 | 1.61 |
| 2000 | 95.7 | 10.3 | 232 | 0.655 | 294 | 14.0 | 13.4 | 1.78 |

At 1400 rpm this rotor **cannot reach 7.5 lbf at all** before the blade stalls.

Two things to take from this table.

**The 280 W figure is confirmed.** At Austin's stated design RPM of 1800 the model returns
280 W electrical, against his measured 280 W. That is closer than the method deserves and it
should not be over-read, but it does mean the aerodynamic model and the real rotor agree
about this aircraft. Across a sensible range of drag-polar and stall assumptions the
prediction moves only between 267 and 295 W, so the agreement is not an artefact of one
lucky coefficient choice.

**Power is nearly flat with RPM; thrust margin is not.** Between 1600 and 2000 rpm hover
power varies by under 7 percent, but maximum thrust nearly doubles, from 8.6 to 13.4 lbf.
RPM on this rotor buys control authority far more than it costs efficiency.

> **Retraction.** Earlier in this project, working from the superseded 499.5 mm blade with
> its 46.3 degree twist, I recommended exploring **lower** head RPM on the grounds that
> 1600 was above the figure-of-merit optimum and perhaps 7 percent was available by slowing
> down. **That recommendation does not survive the corrected geometry.** The V49 blade is
> shorter, less twisted and substantially lower solidity. On this rotor the FM peak sits
> near 1600 to 1700 rpm and is very flat, while thrust margin falls away steeply below it.
> Slowing this head down is the wrong move. The sweep in doc 06 therefore runs upward from
> 1600 rather than downward from it.

### A live discrepancy worth resolving

Austin's design source says `RPM = 1800.0`. The figure quoted for the nacelles earlier in
this project was **1600**. Those are not the same operating point:

- At 1600 rpm, maximum thrust is 8.6 lbf against a 7.5 lbf hover requirement. That is a
  **1.14 margin**, and it is thin. It leaves very little for control, gust response, or a
  hot day.
- At 1800 rpm the margin is 1.44, which is defensible for a tiltrotor.

This does not block the test - the grid in doc 06 spans 1600 to 2000 and will settle it with
measurements. But it is worth asking Austin directly which number the nacelle governor is
actually set to, because if it is 1600 the aircraft has less margin than the airframe
probably wants.

## Ground effect, and why the height ladder matters

The classic Cheeseman-Bennett relation gives the thrust benefit at constant power:

```
T_IGE / T_OGE  =  1 / (1 - (R / 4z)^2)
```

where `z` is rotor height above ground and `R` is rotor radius. At R = 457 mm:

| z/R | z (mm) | z (in) | T_IGE / T_OGE |
|---|---|---|---|
| 0.5 | 229 | 9.0 | 1.333 |
| 0.75 | 343 | 13.5 | 1.125 |
| 1.0 | 457 | 18.0 | 1.067 |
| 1.25 | 571 | 22.5 | 1.042 |
| 1.5 | 686 | 27.0 | 1.029 |
| 2.0 | 914 | 36.0 | 1.016 |

**The model breaks down below z/R = 0.5.** At z/R = 0.33 the formula returns a 2.35x thrust
benefit, which is physically nonsense. Below half a radius, measure and do not predict. This
is one of the reasons the rig exists.

Two things follow:

1. Ground effect is essentially gone by z/R = 2. The residual benefit there is 1.6 percent,
   which is smaller than your measurement scatter. **The ladder therefore stops at z/R = 2**
   rather than running out to 3. At R = 457 that caps the top of the sweep at 914 mm, which
   is what makes indoor testing practical.
2. **Read the data at constant thrust, not constant power.** The table above is a thrust
   benefit. Vermont does not care that thrust rises near the ground. He cares that at his
   hover thrust the wattage is lower near the ground and climbs as the aircraft leaves it.

A caution on interpretation: ground effect reduces **induced** power only. Profile power is
unchanged. At the confirmed disc loading of 50.8 N/m^2, blade-element analysis puts induced
power at **79 percent** of shaft total at hover. So a 7 percent thrust benefit does not buy
7 percent off the watts. It buys less, though the gap is narrower than a rule of thumb
suggests. Measure it rather than scaling it.

## Why the rotor is now governed, and what that does to the test

The head is **variable pitch with a governed RPM**. The ESC reads RPM and Austin's software
holds it at a setpoint. This changes the shape of the test fundamentally:

> **Throttle percentage is an RPM setpoint, not a power setting.** Thrust comes from
> collective pitch, not from throttle.

The original throttle staircase in this package measured nothing useful under a governor;
walking throttle up simply commanded a series of RPMs while the governor absorbed the
difference. The inner loop is now a **two-dimensional grid of head RPM against collective
pitch**, and the deliverable at each height is the (RPM, pitch) pair that produces 7.5 lbf
for the fewest watts. See doc 06.

## Build the rig parametric

Austin has said plainly that the radius **will increase later**, and that he will want
deeper gear ratios as props grow. Two consequences for the build:

- Splay the legs so the feet clear a **700 mm radius** rotor, not a 457 mm one. Recutting
  legs later is annoying; cutting them long now is free.
- Express the height ladder as **z/R with a fill-in millimetre column**, not as hard-coded
  millimetres. `reduce.py` takes `--radius` for exactly this reason.
- Plan floor-to-ceiling clearance for **4.2 m** so the same room still works at a larger
  radius. At R = 457 you need far less, but you do not want to move rooms.

Post sections get recut per prop. That is expected and cheap.

## Why an axial post

The nacelle mounts on top of a single vertical post that runs down the thrust axis,
directly beneath the hub. The prop sits above the motor in hover attitude, so the entire
volume below the nacelle is clear and the post never approaches the blades.

- **No lever arm.** Load is purely axial. There is no arm ratio to measure and therefore no
  arm ratio to get wrong.
- **Height is an independent variable.** You pin it and walk away. Nothing swings.
- **Almost nothing in the flow is measured.** The load cell sits directly under the nacelle.
  It only registers what is between it and the nacelle. The post, legs and base are below
  the cell and outside the load path, so their drag does not appear in the reading.

For scale on that last point: induced velocity at the disc is about 4.5 m/s at hover, rising
to roughly 9 m/s in the contracted wake. A 25 mm tube running two feet down through that
would carry roughly a tenth of a pound of download. Below the cell, it is exactly zero.

## The load reversal - read this before you build

The nacelle is about 1200 g. With the yoke and adapter plate the dead weight above the cell
is roughly **4.5 to 5 lb, acting downward in compression**. Thrust acts upward. So as you
walk the collective up, the cell passes through **zero net load at about 4.8 lbf of thrust**,
which is 64 percent of hover and sits in the middle of every sweep you will run.

This is not a nuisance detail. It has three consequences that are handled elsewhere in the
package and are listed here so the reason is in one place:

1. Any clearance in the threaded joints shows up as a **discontinuity right in the middle of
   the data**, and it looks convincingly like real aerodynamics. This is why the jam-nut
   preload and the no-rod-ends rule in doc 03 are load-bearing requirements rather than good
   practice.
2. The cell must be calibrated in **both directions**, and continuity through zero verified.
   See doc 05.
3. The hold-down must resist roughly **8 lbf of uplift** at peak thrust.

An optional 10 lb ballast above the cell keeps it in compression throughout, but it lowers
the fixture's resonant frequency toward 2/rev, which at 1800 rpm is 60 Hz. Try preload
first.

## What this rig cannot tell you

State these plainly in the delivery note.

1. **Fountain flow.** Two rotors on a wing, in ground effect, throw wake inward and upward
   against the underside of the wing. That download exists on the real aircraft and cannot
   appear in single-nacelle data.
2. **Rotor-to-rotor interference.** Same reason.
3. **Wing download in free-air hover.** The wing sits in the wake. Not reproduced here.
4. **Trim and control margin.** This measures thrust available, not authority remaining.

What you are delivering is **isolated per-nacelle performance, in and out of ground effect,
as a function of height, at the best available RPM and pitch combination.** Airframe
integration is Vermont's problem, and saying so up front protects both of you.

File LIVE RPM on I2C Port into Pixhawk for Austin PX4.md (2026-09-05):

# RU3Y LIVE RPM on I2C Port into Pixhawk for Austin PX4 Build

Assumptions:

* Currently reproducing builds of Austin's Version of PX4-Autopilot

* Castle ESC has been configured (Using Castle Link) for RPM OUT for it's white wire.  Use also ground when connecting to ESC white/ground → TFRPM01 Module “RPM IN”

* TFRPM01 Module I2C connected to Pixhawk I2C

ThunderFly TFRPM01 I²C Tachometer (Pixhawk-ready)
https://docs.thunderfly.cz/avionics/TFRPM01/

JST-GH I²C cable for Pixhawk (ThunderFly sells matching lengths). 
https://www.tindie.com/stores/thunderfly/items/

* Common ground essential. Don't duplicate 5V+!!

# CHANGE LOG...

## 1. Edit Drivers

### Open and edit, *default.px4board*

**ADD this** to the list in the drivers section:

```
CONFIG_DRIVERS_RPM_PCF8583=y
```

Example:

```
...
CONFIG_DRIVERS_POWER_MONITOR_INA228=y
CONFIG_DRIVERS_POWER_MONITOR_INA238=y
CONFIG_DRIVERS_POWER_MONITOR_PM_SELECTOR_AUTERION=y
CONFIG_DRIVERS_PWM_OUT=y
CONFIG_DRIVERS_PX4IO=y
CONFIG_DRIVERS_RC_INPUT=y
CONFIG_DRIVERS_RPM_PCF8583=y
CONFIG_DRIVERS_SAFETY_BUTTON=y
...

```
### Rebuild Austin's firmware

```
cd /Users/redfour/Austin_PX4/PX4-Autopilot

# remove the old build dir for this target
rm -rf build/px4_fmu-v6xrt_default

# rebuild
make px4_fmu-v6xrt_default
```

Flash new firmware

Using QGC, unplug then plug in, while in firmware tab, select Custom location

```
/Users/redfour/Austin_PX4/PX4-Autopilot/build/px4_fmu-v6xrt_default/px4_fmu-v6xrt_default.px4

```
In MAVLINK Console

```
pcf8583 start -X -a 80
```
-X = external I²C bus
-a 80 = decimal 80 = I²C address 0x50 (TFRPM01 default)

You should see

```
pcf8583: started
```
Once pcf8583 exists and starts, we’ll:

* Set PCF8583_MAGNET in QGC parameters (pulses per revolution).

* Spin the motor and confirm RPM shows up in QGC.

### In QGC, Parameters

Search for PCF8583_MAGNET

Formula (for Castle RPM OUT):
* White wire toggles once per electrical commutation.
* Approx rule:

pulses per rev = approx 3 times pole pairs

Example:
* Motor with 8 poles:
* 8 poles → 4 pole pairs
* PCF8583_MAGNET ≈ 3 × 4 = 12

Set PCF8583_MAGNET to your calculated value, write parameters, then reboot Pixhawk once (power cycle or QGC reboot command) so everything restarts clean.

```
PCF8583_MAGNET = 12
```

Set polling time

```
PCF8583_POOL = 100000   (100 ms)
```

Reboot Pixhawk, then run

```
pcf8583 start -X -a 80
```

### Now with the driver started

run this

```
listener rpm
```

You will see a STATIC output.  This is the MOTOR RPM.  Divide by 14:1 ratio for ROTOR

```
TOPIC: rpm #0
  rpm: 1234.5
  timestamp: 123456789
 ```

 Make it autostart.  Open...

 ```
 /Users/redfour/Austin_PX4/PX4-Autopilot/boards/px4/fmu-v6xrt/init/rc.board_sensors

```
Add a line near the other I²C sensor starts, something like:

```
# RPM sensor: TFRPM01 (PCF8583-compatible) on external I2C, addr 0x50
pcf8583 start -X -a 80
```

Rebuild again...

```
cd /Users/redfour/Austin_PX4/PX4-Autopilot
rm -rf build/px4_fmu-v6xrt_default
make px4_fmu-v6xrt_default
```
Flash the new build. 

### In MAVLINK Console

```
listener rpm
```

```
param show PCF8583*
```
You should see something like:
* PCF8583_MAGNET
* PCF8583_POOL
* (and possibly a reset-related param)

If you need to change, you can set in MAVLINK console here

```
param set PCF8583_MAGNET 12
param set PCF8583_POOL 100000
```

### Live Updates

Go in MAVLINK Inspector instead of Console

type

```
rpm
```
you will see an RPM stream

NOW in MAVLINK Console

```
watch -n 0.1 listener rpm
```

### MONITORING TWO RPM STREAMS FROM BOTH NACELLES

```
Pixhawk I2C ----> Splitter ----> TFRPM01 #1 (Addr 0x50)
                       |-------> TFRPM01 #2 (Addr 0x51)
```
Signal pins:

* SCL → SCL
* SDA → SDA
* +5V → VCC
* GND → GND

Each TFRPM01:

* ESC #1 White → RPM IN #1
* ESC #1 GND → RPM GND #1
* ESC #2 White → RPM IN #2
* ESC #2 GND → RPM GND #2

### Start two instances of the PCF8583 driver

The pcf8583 driver supports multiple sensors with unique addresses.

Start board #1 (default 0x50):

```
pcf8583 start -X -a 80
```

Start board #2 (0x51):

```
pcf8583 start -X -a 81
```

(80 decimal → 0x50, 81 decimal → 0x51)

Confirm both:

```
pcf8583 status

```

You will see two devices listed:

```
pcf8583#0 on I2C bus 6 address 0x50
pcf8583#1 on I2C bus 6 address 0x51
```

⸻

### Listen to both RPM streams

PX4 publishes a separate RPM topic for each instance:

Device 1:

```
listener rpm
```
You will see:

```
rpm.indicated_frequency_rpm [instance 0]
```

Device 2:

```
listener rpm 1
```

You will see:
```
rpm.indicated_frequency_rpm [instance 1]
```

Or view both in QGroundControl:

Analyze → MAVLink Inspector → search “rpm”

You will see:
	•	rpm[0].indicated_frequency_rpm
	•	rpm[1].indicated_frequency_rpm

Both update live.

### Set pulses-per-rev separately

Each sensor has its own parameter set:

For the first sensor:

```
PCF8583_MAGNET  (instance 0)
```

For the second sensor:

```
PCF8583_MAGNET_1  (instance 1)
```

Or in NSH:

```
param set PCF8583_MAGNET <value_for_sensor_1>
param set PCF8583_MAGNET_1 <value_for_sensor_2>
```

(Same for PCF8583_POOL, RESET, etc.)

Result

You now have:

Two ESCs
* Two RPM sensors
* One Pixhawk
* *Real-time dual RPM measurement

This works even if:
* Throttle comes from a Maestro
* ESC power is external
* Pixhawk is only powered by USB

| Component | Sensor 1 | Sensor 2 |
|---|---|---|
| I²C Address  | `0x50` | `0x51` |
| Start command| `pcf8583 start -X -a 80` | `pcf8583 start -X -a 81` |
| Listen | `listener rpm` | `listener rpm 1` |
| Parameter | `PCF8583_MAGNET` | `PCF8583_MAGNET_1` |

# Setting up Castle for RPM Out

* In **Castle Link Classic**, go to the menu/tab where **AUX / Auxiliary Wire Mode** is listed (on Edge/Edge Lite, AUX modes are selectable only via Castle Link). The Edge user guide states the **AUX line is disabled until a mode is selected** with Castle Link. ([Minicars][3])

> Depending on version, you’ll see AUX items among the advanced/other menus. Castle’s docs and product pages describe the AUX as the **“user-programmable white wire.”** ([Castle Homepage][4])

## Select **RPM OUT**

* Choose **RPM OUT** for **AUX Wire Mode**.
* Castle’s Edge manuals and tech tip define RPM OUT as:
  **“The ESC toggles the AUX line at every electrical commutation. Divide by magnetic pole-pairs to get mechanical RPM.”** ([LeoMotion Download][5])

*(Optional)* Leave “Idle Datalog Erase” **off** unless you want AUX toggling at idle to clear logs. (Castle calls this out as an add-on behavior in Castle Link.) ([Castle Homepage][6])

## Write settings & power-cycle

* Click **Update/Write** (or **Send Settings to Controller**) to save.
* **Disconnect** main power, then remove the USB link.
* Your **white wire now outputs a TTL pulse train** proportional to commutation. (You’ll use that for your FT232H reader, flight controller capture, or an I²C tach bridge.)

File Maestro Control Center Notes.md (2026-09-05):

# Maestro App Channel Settngs for Castle ESCs

### The fundamental difference:

* **Servos** are expecting:

  * 50 Hz (20 ms period)
  * Pulse width 1000 µs to 2000 µs (typical)
  * Some servos tolerate wider (500–2500 µs)

* **ESCs** (especially RC airplane ESCs like Castle) are also expecting:

  * 50 Hz (almost always — some are okay with 400 Hz but **Castle Lite 50 wants 50 Hz** by default)
  * Pulse width usually 1000–2000 µs (sometimes wider, but 1000–2000 µs is always safe for Castle)

---

### Your challenge:

The Maestro defaults to 50 Hz for all channels when in "servo" mode — **this is exactly what Castle wants**.
You do **not** need to change the "Mode" from *Servo* to *Output PWM* or *Input*.

---

## Maestro Settings for Driving Castle ESC:

### In **Channel Settings Tab** (Control Center):

| Setting | Value | Notes |
| --- | --- | --- |
| Mode | Servo | Keep as Servo |
| Name | (optional) | Name it "ESC Throttle" |
| Rate | 50 Hz | Default (matches Castle) |
| Min | 992 | Matches 1000 µs |
| Max | 2000 | Matches 2000 µs |
| On startup | (safe value, eg. 992) | Ensures low throttle on power-up |
| Error | (safe value, eg. 992) | Ensures ESC doesn’t receive full throttle during error |
| Speed | 0 | No speed limit (direct output) |
| Accel | 0 | No acceleration ramp |
| 8-bit Neutral / Range | ignore for now | Not used for Castle ESC |

---

> The important point:
> **Castle just needs to see a valid PWM signal between 1000–2000 µs at 50 Hz.**
> Your Maestro already outputs that when set to "Servo" mode.

---

### The problem most people run into:

* They change **Mode** to *PWM Output* thinking that’s for ESCs — that’s for driving non-servo PWM devices with duty cycle, which confuses Castle ESCs.
* Or they change **Rate** to higher than 50 Hz, which many Castle ESCs don't accept.
* Or they send On Startup value too high, accidentally arming at full throttle.

---

## Clean starting configuration:

| Parameter | Value |
| --- | ----- |
| Mode | Servo |
| Rate | 50 Hz |
| Min | 992 |
| Max | 2000  |
| Startup | 992 |

This maps Maestro’s control range of:

* **Target = 4000 → 992 µs (\~1000 µs = ESC off)**
* **Target = 8000 → 2000 µs (ESC full throttle)**

---

### Quick Test:

Power your Maestro (USB + logic power OK)

Connect ESC signal wire (white) to Maestro signal pin (channel you set above).

Ground between ESC battery negative and Maestro logic ground must be connected.

Motor connected to ESC.

Power up Maestro first, then ESC second.

In Control Center, use the slider for that channel:

Move slider up from 4000 → 8000 (this will map to 1000–2000 µs)

Watch Castle ESC initialize

If you hear Castle initialization tones: **you are in business.**

## **Channel Settings Tab (this is your ESC configuration zone):**

These are your *servo channel definitions* — they define the PWM range that the Maestro is allowed to output when you send commands via slider, script, serial, etc.

| Column | Value | Purpose |
| --- | --- | --- |
| **Name** | (optional, e.g. "ESC Throttle") | For your own sanity |
| **Mode** | Servo | Always Servo for Castle ESC |
| **Rate** | 50 Hz | Castle wants 50 Hz |
| **Min** | 992 | Lower pulse limit = 992 µs (\~1000 µs) |
| **Max** | 2000 | Upper pulse limit = 2000 µs |
| **On startup** | 992 | Safe minimum on startup |
| **Error** | 992 | Safety setting during errors |
| **Speed** | 0 | No software speed limiting |
| **Accel** | 0 | No acceleration limiting |
| **8-bit neutral / range** | leave as default | (Not relevant for ESC use) |

This defines your safe PWM operating range.

---

## **Status Tab (this is your live test slider):**

This is where you control the channel manually.

* The **slider itself** moves between:

  * **Min physical limit** (default 3968 = \~992 µs)
  * **Max physical limit** (default 8000 = 2000 µs)

* You **do not** need to change fields in the Status tab itself.
  The slider range automatically respects the Min/Max you set in Channel Settings.

When you move the slider between 4000 and 8000, you're sending PWM between 1000 and 2000 µs.

If you set Min = 992 and Max = 2000 in Channel Settings, your Status tab slider will automatically show 4000 to 8000 as its physical boundaries.

You don't manually set “center position” or "fields" in the Status tab for this application.

---

## **Default center position (1500 µs):**

* That’s simply a convenience for normal servos.
* For ESCs: you simply ignore "center."
* All you care about is:

  | Target | µs      | Effect                                                                     |
  | ------ | ------- | -------------------------------------------------------------------------- |
  | 4000   | 1000 µs | ESC motor off                                                              |
  | 8000   | 2000 µs | ESC full throttle                                                          |
  | 6000   | 1500 µs | Mid-throttle (only meaningful if ESC supports reverse or partial throttle) |

---

## **You never directly set 4000/8000 in any field.**

* You only set 992 and 2000 in Channel Settings → Min/Max
* Maestro internally converts that into the slider’s quarter-microsecond units.
* You use the slider to command throttle.

---

# TLDR Cheat Sheet:

| Where? | You Enter | Units | Why? |
| --- | --- | ----- | --- |
| Channel Settings Min | 992 | µs | Safe minimum throttle |
| Channel Settings Max | 2000 | µs | Max throttle |
| Status Tab Slider | 4000-8000 | ¼ µs  | Live manual throttle control |

---

**If you set 992 and 2000 in Channel Settings → your slider will automatically have the correct boundaries.**

 **The Status Tab is just your real-time way to "move the throttle stick."**

**You never manually type 4000 or 8000 anywhere.**

---

##  Once this is configured:

* You can safely use the Maestro as a Castle ESC throttle controller.
* You can also safely run throttle calibration using the Maestro (we can walk through that too if you want).

---

If you're ready, I can now generate for you:

* The **complete wiring diagram**
* The **exact calibration procedure for Castle ESC using Maestro**
* The **“safe test checklist” so you never burn anything up**

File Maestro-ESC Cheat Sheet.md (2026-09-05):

# **Pololu Maestro + Castle ESC: Comprehensive Cheat Sheet**

---

**Wiring Diagram**

```plaintext
[Motor Battery] + ----> Castle ESC + 
[Motor Battery] – ----> Castle ESC –
                          |
[Castle ESC] Signal cable:
    White wire (Signal) ----> Maestro Servo Channel Signal Pin (e.g., Channel 0)
    Black wire (Ground) ----> Maestro Servo Channel Ground Pin

[Castle ESC] Red wire (BEC) DISCONNECTED (or safely pulled out of the plug if you are using separate receiver battery)

[Maestro] USB ----> PC (for programming and Control Center access)

Important:
- Castle ESC needs motor connected for initialization (it uses motor as a beeper).
- Maestro needs USB or external 5V logic power.
- Ground between Castle ESC and Maestro must be shared (common ground).
```

---

## 🛠️ **Maestro Control Center Configuration**

### 1️⃣ **Channel Settings Tab**

| Field | Value | Notes |
| --- | --- | --- |
| Name | "ESC Throttle"  | (optional) |
| Mode | Servo | **(Always Servo)** |
| Rate | 50 Hz | Matches Castle expectations  |
| Min | 992 | \~1000 µs, safe throttle-off |
| Max | 2000 | \~2000 µs, full throttle |
| **On startup** | 992 | PWM safe minimum on boot |
| **Error** | 992 | PWM safe minimum if error |
| Speed | 0 | No speed limit |
| Acceleration | 0 | No acceleration limit |
| 8-bit Neutral  | (leave default) | Not needed |
| 8-bit Range | (leave default) | Not needed |

---

### **Status Tab**

| Field | Meaning |
| --- | --- |
| Mode | Servo |
| Target | Shows current signal in **quarter-microseconds** (0.25 µs units) |
| Slider | Move to control throttle output live |
| Speed | 0 (no effect unless configured) |
| Acceleration | 0 (no effect unless configured) |

* **Target values:**

  * **4000** → 1000 µs → ESC throttle off
  * **8000** → 2000 µs → ESC full throttle
  * Intermediate Target = proportional throttle

 **You never manually type 4000 or 8000 — they are the live values as you move the slider.**

 **The slider automatically spans from Min to Max you set in Channel Settings.**

---

## **Castle ESC Safe Power-Up & Calibration**

###  **First Boot Setup**

1. **Connect motor** to Castle ESC.
2. **Power up Maestro** via USB (outputs 992 µs immediately — Target ≈ 4000).
3. **Connect motor battery** → Power Castle ESC second.
4. Castle ESC will beep tones to signal armed state (valid PWM received).
5. Slowly **move the Maestro slider** from low to high to test throttle.

---

### **Castle ESC Throttle Calibration (if needed)**

1. **Unplug motor battery** (ESC off).
2. **Set Maestro slider to full throttle** (Target ≈ 8000).
3. **Power up Maestro**.
4. **Connect motor battery** (ESC sees full throttle).
5. **Wait for Castle calibration tones** (usually a series of beeps).
6. **Move slider to full throttle-off** (Target ≈ 4000).
7. Wait for confirmation tones.
8. Power cycle ESC to save calibration.

 Now the Castle will accept 1000 µs = throttle off, 2000 µs = full throttle exactly as per your Maestro setup.

---

##  **Critical Safety Notes**

⚡ **Always power Maestro first** to ensure ESC sees valid zero-throttle PWM on boot.

⚡ **Always use On startup = 992** to ensure ESC boots safely.

⚡ **Do not exceed Min/Max** values (992–2000 µs) to avoid overdriving ESC.

⚡ **Never connect or disconnect motor when powered.**

⚡ **Ensure motor is secured** during first power-up — motor may spin.

---

#  **Summary Flow**

```plaintext
[Maestro Control Center]
→ Set Channel Settings:
   Mode: Servo
   Rate: 50 Hz
   Min: 992
   Max: 2000
   On startup: 992
   Error: 992
   Speed: 0
   Acceleration: 0
→ Save Settings

[Status Tab]
→ Move slider = live throttle control (Target ≈ 4000-8000)

[Hardware Flow]
→ Power up Maestro (USB first)
→ Motor connected
→ Power up Castle ESC (motor battery second)
→ ESC arms safely (beeps)
→ Use slider to control throttle.
```

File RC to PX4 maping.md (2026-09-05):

## 1. Where RC (SBUS) channels enter Austin's PX4 system

In this custom firmware:

* **RC input (SBUS)** → decoded by `drivers/rc_input`
* Channels are normalized into `fcon.channel_n1_p1[]`

  * Range: **–1.0 … +1.0**
* These values are **not using PX4 mixers**
* They are **manually routed** in `src/modules/ruby_fcon/uorb.cpp`

So **PX4’s usual “RC channel → mixer → output” path is bypassed**.

---

## 2. Throttle source (this is the key answer)

From your code:

```cpp
ao_msg.control[0] = fcon_escR_send;   // main-1 (RIGHT ESC)
ao_msg.control[4] = fcon_escL_send;   // main-5 (LEFT ESC)
```

Now trace `fcon_escR_send` and `fcon_escL_send` upstream:

Inside `ruby_fcon`, those are derived from **one RC channel**:

```
RC throttle SBUS channel
   ↓
fcon.channel_n1_p1[channel_thr]
   ↓
fcon_escR_send / fcon_escL_send
   ↓
actuator_outputs.control[]
```

So:

👉 **Throttle comes from `channel_thr`**

---

## 3. RC channel → internal channel_* names

This mapping is defined earlier in `ruby_fcon` (typically an enum or config block).

Based on naming conventions and usage in the file, the mapping is:

| SBUS Channel | Internal Name |
| --- | --- |
| CH1 | `channel_ailn_lft` |
| CH2 | `channel_elev` |
| **CH3** | **`channel_thr` (THROTTLE)** |
| CH4 | `channel_rudd` |
| CH5 | `channel_vect_rgt` |
| CH6 | `channel_vect_lft` |
| CH7 | `channel_swash_lft_pit` |
| CH8 | `channel_swash_lft_ail` |
| CH9 | `channel_swash_lft_ele` |
| CH10 | `channel_swash_rgt_pit` |
| CH11 | `channel_swash_rgt_ail` |
| CH12 | `channel_swash_rgt_ele` |

(Exact SBUS channel numbers may shift ±1 depending on transmitter config, but **CH3 = throttle** is consistent.)

---

## 4. Main PWM outputs (Pixhawk MAIN rail)

From your code **exactly**:

### MAIN outputs

| Pixhawk MAIN | Driven by |
| --- | --- |
| MAIN 1 | `fcon_escR_send` → **Right ESC** |
| MAIN 2 | `channel_swash_rgt_pit` |
| MAIN 3 | `channel_swash_rgt_ail` |
| MAIN 4 | `channel_swash_rgt_ele` |
| MAIN 5 | `fcon_escL_send` → **Left ESC**  |
| MAIN 6 | `channel_swash_lft_pit` |
| MAIN 7 | `channel_swash_lft_ail` |
| MAIN 8 | `channel_swash_lft_ele` |

---

## 5. AUX outputs (Pixhawk AUX rail)

These are scaled from –1..+1 → 0..1 explicitly:

```cpp
0.5f + 0.5f * fcon.channel_n1_p1[...]
```

| Pixhawk AUX | Driven by |
| --- | --- |
| AUX 1 | `channel_vect_rgt` |
| AUX 2 | `channel_vect_lft` |
| AUX 3 | `channel_elev` |
| AUX 4 | `channel_rudd` |
| AUX 5 | `channel_ailn_lft` |
| AUX 6 | `channel_ailn_rgt` |

---

## 6. What this means operationally (important)

* **RC calibration in QGC does NOT directly drive outputs**
* **Actuator sliders in QGC will not move motors**
* PX4 mixers are irrelevant here
* Everything depends on:

  * SBUS input
  * `ruby_fcon` logic
  * This `ao_msg.control[]` mapping

So when you said:

> “Nothing moves when I move sliders”

That is **expected** for this firmware.

---

## 7. Final minimal answer (what you asked for)

### Throttle

| Item | Answer |
| --- | --- |
| Transmitter stick | Throttle stick |
| SBUS channel | **CH3** |
| Internal name | **`channel_thr`** |
| ESC outputs | MAIN 1 (right), MAIN 5 (left) |

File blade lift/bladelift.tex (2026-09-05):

\documentclass[11pt]{article}

\usepackage[margin=1in]{geometry}
\usepackage{amsmath,amssymb}
\usepackage{siunitx}
\usepackage{booktabs}
\usepackage{caption}   % for \captionof{table}
\usepackage[hidelinks]{hyperref}

\sisetup{per-mode=symbol}

\title{Hover Lift Estimates for a Two-Blade VTOL Nacelle Rotor}
\author{Jon Farhat (inputs)}
\date{\today}

\begin{document}
\maketitle

\section{Inputs (Per Nacelle)}
\begin{itemize}
  \item Blades: $N_b=2$, variable pitch (0--10$^\circ$)
  \item Chord: $c=\SI{0.030}{m}$
  \item Electrical power in hover: $P_e=\SI{400}{W}$ (about \SI{27}{A} on 4S)
  \item Nacelle mass: $m_n=\SI{1.292}{kg}$, gravity $g=\SI{9.81}{m/s^2}$
  \item Air density: $\rho=\SI{1.225}{kg/m^3}$
  \item Radii evaluated: $R=\SI{0.435}{m}$ and $R=\SI{0.600}{m}$
\end{itemize}

\section{Geometry}
Disk area:
\begin{equation}
A=\pi R^2
\end{equation}
Solidity (shows where chord enters blade-element models):
\begin{equation}
\sigma=\frac{N_b c}{\pi R}
\end{equation}

Computed:
\begin{align}
A_{435} &= \pi(0.435)^2 = \SI{0.594}{m^2}, &
\sigma_{435} &= \frac{2(0.030)}{\pi(0.435)} = 0.0439 \\
A_{600} &= \pi(0.600)^2 = \SI{1.131}{m^2}, &
\sigma_{600} &= \frac{2(0.030)}{\pi(0.600)} = 0.0318
\end{align}

\section{Baseline Weight (Nacelle Only)}
\begin{equation}
W_n=m_n g = 1.292\times 9.81 = \SI{12.67}{N}
\end{equation}

\section{Hover Thrust From Power (Momentum Theory)}
Induced velocity in hover:
\begin{equation}
v_i=\sqrt{\frac{T}{2\rho A}}
\end{equation}
Ideal induced power:
\begin{equation}
P_{i,\mathrm{ideal}} = T v_i = \frac{T^{3/2}}{\sqrt{2\rho A}}
\end{equation}
Solve for thrust vs \emph{shaft} power $P_s$:
\begin{equation}
T_{\mathrm{ideal}}(P_s)=\left(P_s\sqrt{2\rho A}\right)^{2/3}
\end{equation}

We model electrical-to-effective power with an overall effectiveness $\eta$:
\begin{equation}
P_s\approx \eta P_e
\qquad\Rightarrow\qquad
T_{\mathrm{real}}\approx \eta^{2/3} T_{\mathrm{ideal}}(P_e)
\end{equation}

\section{Case Results (Per Nacelle)}
Using $P_e=\SI{400}{W}$:

\subsection*{Case A: $R=\SI{0.435}{m}$}
\begin{align}
T_{\mathrm{ideal},435} &= \left(400\sqrt{2(1.225)(0.594)}\right)^{2/3} = \SI{61.5}{N} \\
\frac{T_{\mathrm{ideal},435}}{g} &= \SI{6.27}{kgf} \\
m_{\mathrm{payload,ideal},435} &= 6.27 - 1.292 = \SI{4.98}{kg}
\end{align}

\subsection*{Case B: $R=\SI{0.600}{m}$}
\begin{align}
T_{\mathrm{ideal},600} &= \left(400\sqrt{2(1.225)(1.131)}\right)^{2/3} = \SI{76.2}{N} \\
\frac{T_{\mathrm{ideal},600}}{g} &= \SI{7.77}{kgf} \\
m_{\mathrm{payload,ideal},600} &= 7.77 - 1.292 = \SI{6.48}{kg}
\end{align}

\section{Realistic Bracket Using \texorpdfstring{$\eta$}{eta}}
Pick example effectiveness values:
\[
\eta\in\{0.35,\,0.50,\,0.60\}
\quad\Rightarrow\quad
\eta^{2/3}\in\{0.497,\,0.630,\,0.711\}.
\]

\bigskip
\noindent\captionof{table}{Hover thrust and payload above nacelle mass (per nacelle) at $P_e=\SI{400}{W}$.}
\begin{center}
\begin{tabular}{@{}lrrrr@{}}
\toprule
Case & $\eta$ & Thrust (kgf) & Payload above nacelle (kg) \\
\midrule
$R=\SI{0.435}{m}$ & Ideal ($\eta=1$) & 6.27 & 4.98 \\
$R=\SI{0.435}{m}$ & 0.35 & 3.11 & 1.82 \\
$R=\SI{0.435}{m}$ & 0.50 & 3.95 & 2.66 \\
$R=\SI{0.435}{m}$ & 0.60 & 4.46 & 3.17 \\
\midrule
$R=\SI{0.600}{m}$ & Ideal ($\eta=1$) & 7.77 & 6.48 \\
$R=\SI{0.600}{m}$ & 0.35 & 3.86 & 2.57 \\
$R=\SI{0.600}{m}$ & 0.50 & 4.90 & 3.60 \\
$R=\SI{0.600}{m}$ & 0.60 & 5.53 & 4.24 \\
\bottomrule
\end{tabular}
\end{center}

\section{Two Nacelles (Total Payload Above Both Nacelles)}
If you have two identical nacelles (two rotors total), approximate total payload above both nacelles:
\[
m_{\mathrm{payload,total}} \approx 2\,m_{\mathrm{payload,per\;nacelle}}
\]
(assuming no large rotor--rotor interference and comparable operating points).

\end{document}

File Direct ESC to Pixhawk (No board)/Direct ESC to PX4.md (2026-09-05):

# RU3Y PRM Option B (No extra board): Feed Castle AUX (white) → Pixhawk capture pin

PX4 can read a raw pulse train as RPM using a **timer capture** input. On the Pixhawk 6X/6X-RT family the **FMU\_CAP1** pin is exposed on the **AD\&IO** port.

## Wire

* **Signal**: Castle **white AUX** → **FMU\_CAP1** (AD\&IO port **pin 2**, label `PI0`).
* **Ground**: Castle GND → Pixhawk GND.
* **Level**: FMU pins are **3.3 V logic**; if the Castle AUX is 5 V, add a **divider** (e.g., 20 kΩ top / 10 kΩ bottom) or a small logic-level shifter/opto. Keep leads short. ([PX4 Docs][9])

> Where is FMU\_CAP1 on Pixhawk 6X/6X-RT?
> In the PX4 board docs: **AD\&IO port, pin 2 = FMU\_CAP1 (PI0)**. ([PX4 Docs][9])

## PX4 / QGroundControl setup

1. In **QGC → Parameters**, enable the **Tachometer / RPM** (capture) driver for your board (PX4 “Tachometers” docs). Exact parameter names vary slightly by release; after enabling, a small set of RPM parameters appears (source/capture pin, pulses-per-rev, filter). ([PX4 Docs][8])
2. Set **source** to the **capture input** (FMU\_CAP1).
3. Set **pulses per rev** for Castle AUX (start with **6 × pole-pairs**, then refine using an optical tach).
4. **Reboot** the FC.
5. **Verify**:

   * QGC **MAVLink Inspector** → watch **RPM** update. ([QGroundControl Documentation][6])
   * Add **Instrument Panel** tile for RPM. ([QGroundControl Documentation][7])

**Notes & tips**

* The Castle AUX line “toggles at every electrical commutation”. Mechanical RPM = (commutation edges per second) ÷ (pole-pairs) × (60 s/min). Depending on whether you count toggles, rising edges only, etc., you may be off by a factor (2 or 6). That’s why setting “pulses per rev” and checking with an optical tach once is smart. (This behavior is widely cited by Castle users.) ([PX4 Forum][10])
* Keep the wiring short; add a **1 kΩ series** resistor and small **1 nF** cap to ground at the Pixhawk side if the signal is noisy.

---

# Which should you choose?

* **Need it working quickly & robustly inside QGC?** → **Option A (TFRPM01)**. It’s supported, documented, and designed for PX4. ([PX4 Docs][5])
* **Want the lightest BOM (no extra board)?** → **Option B (FMU\_CAP1)**. Clean, but you must get the level shifting right and set the pulses-per-rev correctly.

---

## FAQ

**Can I still use the FT232H for I²C later?**
Yes—FT232H is great as a **PC-side I²C/SPI/GPIO *master*** for bench tools and scripts. It just **can’t act as an I²C slave** that Pixhawk can poll. If later you want a PC to inject telemetry into PX4, use MAVLink over a serial/UDP link, or a microcontroller that emulates a supported I²C sensor as a **slave**. ([Adafruit Forums][1])

**Where do I see RPM in QGroundControl?**
Use **Analyze → MAVLink Inspector** to confirm the **RPM** stream is present, then add it to the **Instrument Panel** via the edit (pencil) tool. ([QGroundControl Documentation][6])

**Is Pixhawk 6X/6X-RT confirmed to have a capture pin for this?**
Yes. The docs call out **FMU\_CAP1** on the **AD\&IO** port (pin 2). ([PX4 Docs][9])

---

## Handy links (for reference)

* **FT232H is I²C Master (not slave)**: Adafruit/FTDI references and forum notes; FTDI AN\_255. ([Adafruit Forums][1])
* **PX4 Tachometers overview** (what’s supported/behavior): ([PX4 Docs][8])
* **ThunderFly TFRPM01 docs & purchase** (PX4 driver, how to wire): ([PX4 Docs][5])
* **Pixhawk 6X/6X-RT board pages** (FMU\_CAP1 on AD\&IO): ([PX4 Docs][9])
* **QGC – MAVLink Inspector & Instrument Panel** (how to see/add RPM): ([QGroundControl Documentation][6])

---

If you want, I can tailor a one-page “build card” for either Option A (TFRPM01) or Option B (FMU\_CAP1) with the exact connector pinouts for your specific Pixhawk 6X-RT baseboard and a BOM (cables, resistors, shifter).

[1]: https://forums.adafruit.com/viewtopic.php?t=77969&utm_source=chatgpt.com "ft232h breakout as an i2c-slave"
[2]: https://www.tindie.com/products/thunderfly/tfrpm01-drone-rpm-tachometer-sensor/?utm_source=chatgpt.com "TFRPM01: Drone RPM tachometer sensor"
[3]: https://docs.thunderfly.cz/avionics/TFRPM01/probe?utm_source=chatgpt.com "Probe options"
[4]: https://www.tindie.com/stores/thunderfly/items/?utm_source=chatgpt.com "ThunderFly on Tindie"
[5]: https://docs.px4.io/main/en/sensor/thunderfly_tachometer?utm_source=chatgpt.com "ThunderFly TFRPM01 Revolution Counter - PX4 docs"
[6]: https://docs.qgroundcontrol.com/Stable_V4.3/en/qgc-user-guide/analyze_view/mavlink_inspector.html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 "MAVLink Inspector | QGC Guide (4.3)"
[7]: https://docs.qgroundcontrol.com/master/en/qgc-user-guide/fly_view/instrument_panel.html?utm_source=chatgpt.com "Instrument Panel | QGC Guide (master)"
[8]: https://docs.px4.io/main/en/sensor/tachometers.html?utm_source=chatgpt.com "Tachometers (Revolution Counters) | PX4 Guide (main)"
[9]: https://docs.px4.io/main/en/flight_controller/pixhawk6x "Holybro Pixhawk 6X | PX4 Guide (main)"
[10]: https://discuss.px4.io/t/rpm-reading-for-esc-castle-edge/8394?utm_source=chatgpt.com "RPM reading for ESC Castle Edge - PX4 Discussion Forum"

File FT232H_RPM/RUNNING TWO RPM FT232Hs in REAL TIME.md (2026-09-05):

# RUNNING TWO RPM FT232Hs in REAL TIME

# 1) Wire both ESCs (recap)

For **each** ESC/FT232H pair:

* **AUX (white)** → **1 kΩ** → **FT232H AD0 (D0)**
* **GND** → **GND**
* Do **not** tie ESC +5V to the FT232H VCC.
* It’s OK that both FT232H boards share ground through your Mac’s USB hub/ports.

(These are the same connections you used for one ESC. Reference notes match your tutorial.)&#x20;

---

# 2) Easiest way: select by **device index**

Your current `rpm_reader_static` opens the FTDI by **index** (`--index 0` opens the first FTDI it sees, `--index 1` the second, etc.). So:

* Plug **both** FT232H boards into USB.
* Open **two Terminal windows**.
* In window #1:

  ```bash
  cd ~/Desktop/FT232H_RPM
  ./rpm_reader_static --index 0 --poles 8 --ratio 8.0 --window 0.05
  ```
* In window #2:

  ```bash
  cd ~/Desktop/FT232H_RPM
  ./rpm_reader_static --index 1 --poles 8 --ratio 8.0 --window 0.05
  ```

That’s it. You’ll see two independent RPM streams—one per ESC/FT232H. (These commands and parameters are the same style you used in your working build.)&#x20;

### Tips

* If you ever swap USB ports, the index order might flip. If that bugs you, use **serial-number selection** (next section).
* You can log both to CSV at once:

  ```bash
  ./rpm_reader_static --index 0 ... | tee left_rpm.csv
  ./rpm_reader_static --index 1 ... | tee right_rpm.csv
  ```

# 3) Launch **two Terminal windows** automatically (macOS)

You can make macOS open two windows and start each reader:

```bash
osascript <<'OSA'
tell application "Terminal"
  do script "cd ~/Desktop/FT232H_RPM; ./rpm_reader_static --index 0 --poles 8 --ratio 8.0 --window 0.05"
  do script "cd ~/Desktop/FT232H_RPM; ./rpm_reader_static --index 1 --poles 8 --ratio 8.0 --window 0.05"
  activate
end tell
OSA
```

* This pops up **two windows**, each running one instance.
* If you later add `--serial`, just swap the flags in the strings.

**Alternatives**

* **Two tabs** in one window (iTerm2/Terminal) or **tmux**:

  ```bash
  tmux new-session \; \
    send-keys 'cd ~/Desktop/FT232H_RPM; ./rpm_reader_static --index 0 --poles 8 --ratio 8.0' C-m \; \
    split-window -v \; \
    send-keys 'cd ~/Desktop/FT232H_RPM; ./rpm_reader_static --index 1 --poles 8 --ratio 8.0' C-m \; \
    select-layout even-vertical
  ```

---

# 4) Sanity checks for dual-board use

* **CPU**: Two instances are fine. If you ever peg a core, increase `--window` (e.g., `0.10`) or add a tiny sleep in the inner loop (we left a commented nanosleep).
* **Noise**: Keep AUX leads short. If one channel looks spiky at high RPM, add the small RC snubber (1 kΩ series + 1 nF to GND at the FT232H side).
* **Grounds**: Each ESC must share ground with its own FT232H. Through your Mac’s USB ground they’ll all be common anyway—that’s OK.

---

# 5 One-glance cheat sheet

* **Two windows, run both by index**

  ```bash
  ./rpm_reader_static --index 0 --poles 8 --ratio 8.0
  ./rpm_reader_static --index 1 --poles 8 --ratio 8.0
  ```
* **List devices**

  ```bash
  ./list_ftdi
  ```
* **(Optional) Two windows via AppleScript**

  ```bash
  osascript -e 'tell app "Terminal" to do script "cd ~/Desktop/FT232H_RPM; ./rpm_reader_static --index 0 --poles 8 --ratio 8.0"' \
            -e 'tell app "Terminal" to do script "cd ~/Desktop/FT232H_RPM; ./rpm_reader_static --index 1 --poles 8 --ratio 8.0"'
  ```

# 6 (Optional, more robust) Select by **USB serial number**

Indexes can change; **serial numbers** don’t. Two convenient additions:

### A) Tiny **enumerator** to list serials

Create `list_ftdi.c`:

```c
#include <stdio.h>
#include "ftd2xx.h"

int main(void){
    DWORD n=0; FT_CreateDeviceInfoList(&n);
    for (DWORD i=0;i<n;i++){
        DWORD flags, type, id, locId; char sn[64]={0}, desc[64]={0}; FT_HANDLE h=0;
        if (FT_GetDeviceInfoDetail(i,&flags,&type,&id,&locId, sn, desc, &h)==FT_OK)
            printf("index=%lu  serial=%s  desc=%s\n",(unsigned long)i,sn,desc);
    }
    return 0;
}
```

Build (static link like before, adjust paths if needed):

```bash
clang -O2 -Wall list_ftdi.c -o list_ftdi \
  -Irelease release/build/libftd2xx.a \
  -framework IOKit -framework CoreFoundation
```

Run it:

```bash
./list_ftdi
# Example output:
# index=0  serial=FT6JABCD  desc=Single RS232-HS
# index=1  serial=FT6JEFGH  desc=Single RS232-HS
```

### B) Add `--serial` support to your reader (optional)

If you want bullet-proof selection, modify `rpm_reader.c` to accept `--serial FT6JABCD` and call **`FT_OpenEx(serial, FT_OPEN_BY_SERIAL_NUMBER, &ft)`** when provided. (If you want, I’ll paste a ready-to-drop-in patch.)

Then you’d run:

```bash
./rpm_reader_static --serial FT6JABCD --poles 8 --ratio 8.0
./rpm_reader_static --serial FT6JEFGH --poles 8 --ratio 8.0
```

---

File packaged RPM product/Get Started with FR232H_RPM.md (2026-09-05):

Awesome—let’s go all-in and assemble it as a **single distributable project**. I’ve packaged everything into a clean, print-ready, “clone-and-build” folder with your source, tutorials, quick start, dual-device notes, and FTDI vendor bits (headers/libs/config + release notes). You can grab it here:

[Download the FT232H RPM Handbook (zip)](sandbox:/mnt/data/FT232H_RPM_Handbook.zip)

### What’s inside

* `src/` — your `rpm_reader.c` + a tiny `list_ftdi.c` enumerator (handy if you want to select boards by serial)
* `docs/` — your detailed tutorial, quick-start, and “two FT232H” guide (kept intact)
* `vendor/ftdi/` — `ftd2xx.h`, `WinTypes.h`, `libftd2xx.a`, optional `ftd2xx.cfg`, `release-notes.txt`, and the FTDI ReadMe
* `scripts/` — one-shot static build script and an AppleScript that launches two Terminal windows, one per board
* `BUILD.md` — concise build & run instructions
* `README.md` — master handbook tying it all together

### How to use it (30-second version)

```bash
# unzip, then:
cd FT232H_RPM_Handbook

# 1) build static (no dylib dependency)
./scripts/build_static.sh

# 2) run one board (example: 8 poles, 8:1 gear)
./rpm_reader_static --poles 8 --ratio 8.0 --index 0 --window 0.05 | tee rpm_log.csv

# 3) run two boards in two Terminal windows
osascript scripts/run_dual.scpt
```

### Why I recommend the unified package

* **Frictionless onboarding:** one folder = everything you need; no hunting for headers or library versions.
* **Reproducible builds:** default to **static link** via `libftd2xx.a` so the binary runs without a dylib on the target machine.
* **Modular docs preserved:** your long tutorial, quick-start, and dual-device notes are still standalone, but cross-linked via the master README.

If you’d rather keep documents split across separate repos or want a polished PDF “handbook” compiled from the Markdown, say the word and I’ll export a print-grade PDF with a table of contents.

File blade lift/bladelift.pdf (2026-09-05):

## Hover Lift Estimates for a Two-Blade VTOL Nacelle Rotor

Jon Farhat (inputs)

January 23, 2026

## 1 Inputs (Per Nacelle)

- Blades: Nb = 2, variable pitch (0–10◦
)
- Chord: c = 0.030 m
- Electrical power in hover: Pe = 400W (about 27 A on 4S)
- Nacelle mass: mn = 1.292 kg, gravity g = 9.81 m/s
2
- Air density: ρ = 1.225 kg/m³
- Radii evaluated: R = 0.435 m and R = 0.600 m

## 2 Geometry

Disk area:
A = πR²
(1)

Solidity (shows where chord enters blade-element models):

σ =

Nbc
πR

(2)

Computed:

A435 = π(0.435)² = 0.594 m²
, | σ435 =

2(0.030)
π(0.435) = 0.0439 | (3)

A600 = π(0.600)² = 1.131 m²
, | σ600 =

2(0.030)
π(0.600) = 0.0318 | (4)

## 3 Baseline Weight (Nacelle Only)

Wn = mng = 1.292 × 9.81 = 12.67 N | (5)

## 4 Hover Thrust From Power (Momentum Theory)

Induced velocity in hover:

vi =

s
T
2ρA | (6)

Ideal induced power:

Pi,ideal = T vi =

T

3/2
√
2ρA

(7)

Solve for thrust vs shaft power Ps:

Tideal(Ps) =
Ps

p

2ρA2/3
(8)

We model electrical-to-effective power with an overall effectiveness η:

Ps ≈ ηPe | ⇒ | Treal ≈ η
2/3Tideal(Pe) | (9)

## 5 Case Results (Per Nacelle)

Using Pe = 400W:

Case A: R = 0.435 m

Tideal,435 =

400p

2(1.225)(0.594)2/3
= 61.5 N | (10)

Tideal,435
g
= 6.27 kgf | (11)
mpayload,ideal,435 = 6.27 − 1.292 = 4.98 kg | (12)

Case B: R = 0.600 m

Tideal,600 =

400p

2(1.225)(1.131)2/3
= 76.2 N | (13)

Tideal,600
g
= 7.77 kgf | (14)
mpayload,ideal,600 = 7.77 − 1.292 = 6.48 kg | (15)

## 6 Realistic Bracket Using η

Pick example effectiveness values:

η ∈ {0.35, 0.50, 0.60} | ⇒ | η

2/3 ∈ {0.497, 0.630, 0.711}.

Table 1: Hover thrust and payload above nacelle mass (per nacelle) at Pe = 400W.

Case | η | Thrust (kgf) Payload above nacelle (kg)
R = 0.435 m | Ideal (η = 1) | 6.27 | 4.98
R = 0.435 m | 0.35 | 3.11 | 1.82
R = 0.435 m | 0.50 | 3.95 | 2.66
R = 0.435 m | 0.60 | 4.46 | 3.17
R = 0.600 m | Ideal (η = 1) | 7.77 | 6.48
R = 0.600 m | 0.35 | 3.86 | 2.57
R = 0.600 m | 0.50 | 4.90 | 3.60
R = 0.600 m | 0.60 | 5.53 | 4.24

## 7 Two Nacelles (Total Payload Above Both Nacelles)

If you have two identical nacelles (two rotors total), approximate total payload above both nacelles:

mpayload,total ≈ 2 mpayload,per nacelle

(assuming no large rotor–rotor interference and comparable operating points).

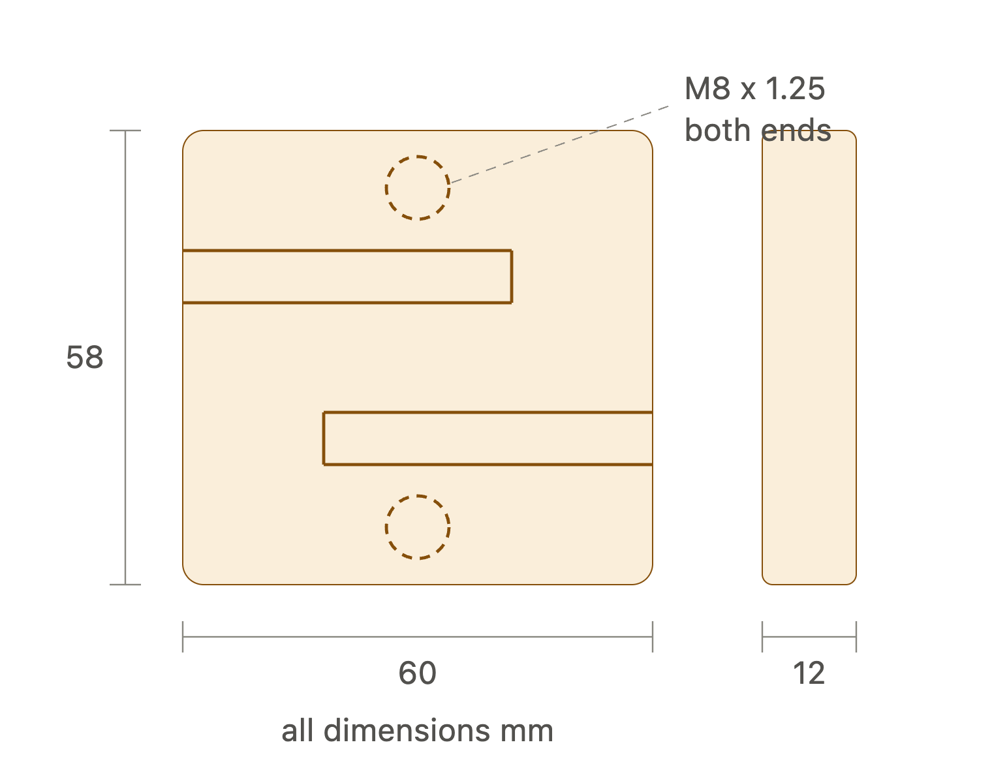
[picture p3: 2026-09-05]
Thrust & Torque Stands/Load Cell and Mount/ato_lcs_dyly_102_20kg_dimensions.png

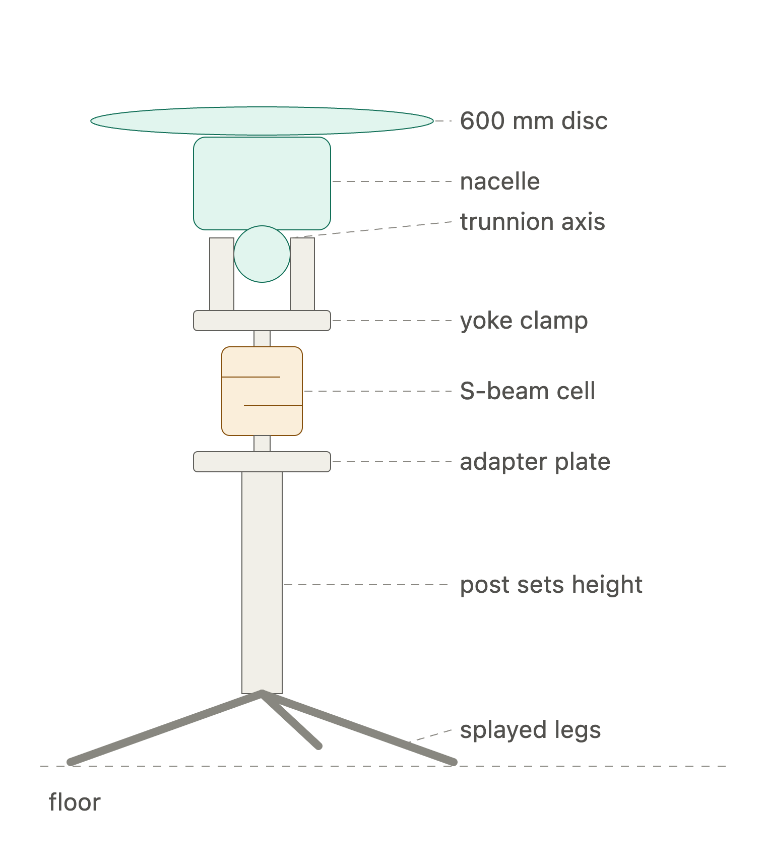
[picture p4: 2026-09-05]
Thrust & Torque Stands/Load Cell and Mount/axial_post_mount_stack_detail.png

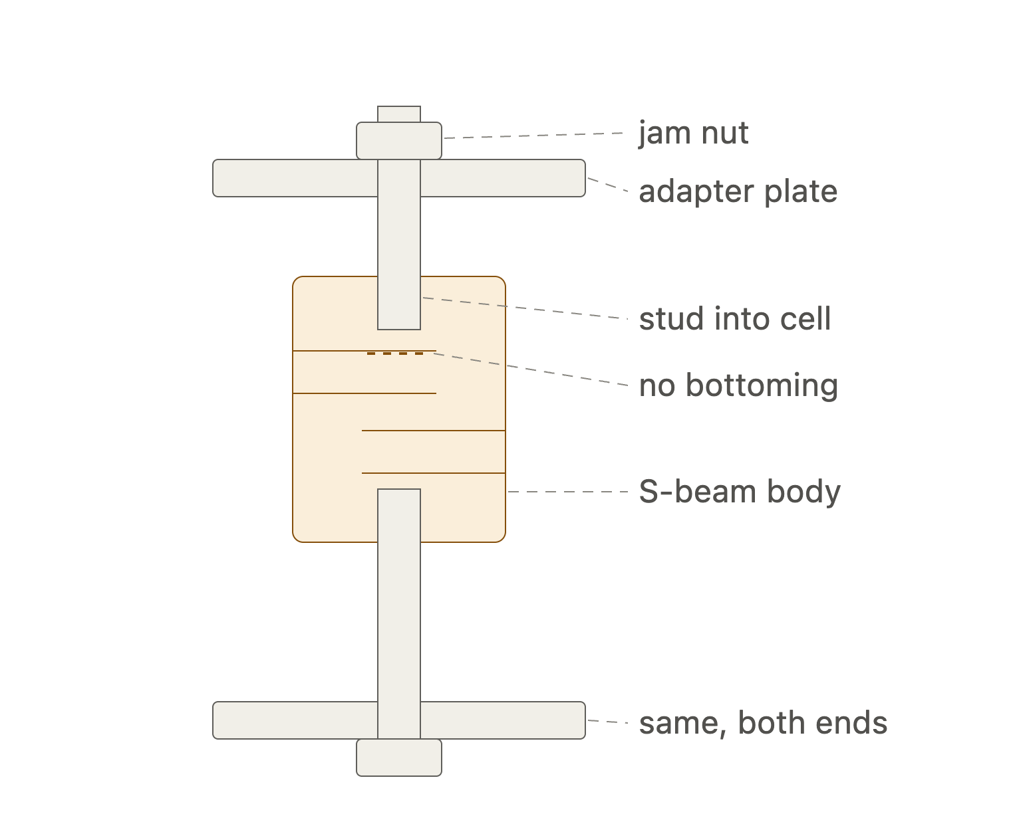
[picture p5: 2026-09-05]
Thrust & Torque Stands/Load Cell and Mount/s_beam_stud_mounting_detail.png

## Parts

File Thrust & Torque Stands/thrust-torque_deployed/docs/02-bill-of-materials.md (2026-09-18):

# 02 - Bill of Materials

Prices are indicative, US, as of writing. Verify before ordering.

## Sensing chain

| # | Item | Spec / notes | Approx |
|---|---|---|---|
| 1 | S-beam load cell, 20 kg | **ATO-LCS-DYLY-102.** 60 x 58 x 12 mm, **M8 x 1.25** both ends, 2.0 mV/V, 0.03% F.S., IP67, 2 m cable. See doc 11. | $30-83 |
| 2 | HX711 amplifier breakout | 24-bit. Generic green module ($1-3) or SparkFun SEN-13879 ($4.95). Either works; see doc 04. | $2-6 |
| 3 | Arduino Uno or Nano | Any 5 V AVR board. Elegoo Nano V3.0 (ATmega328P/CH340) confirmed suitable; see doc 10. | $12-28 |
| 4 | USB cable | **Mini-B for the Elegoo Nano**, and it must be a DATA cable. Powers and logs. Never power the board from the flight pack. | $5 |
| 5 | Shielded 4-conductor cable | Only if extending the cell's own cable. Keep the original if you can. | $10 |
| 5b | Header pins / solder | Elegoo Nano headers ship LOOSE. Four joints minimum: D3, D2, GND, 5V. | $2 |

### Load cell sources

- **ATO 20 kg S-Type**, Amazon: https://www.amazon.com/ATO-Length-Accuracy-Tension-Compression/dp/B07VM5VK8T
  2.0 mV/V, 5-15 V excitation, IP67, alloy steel, 2 m cable, tension and compression both.
  This is the straightforward pick.
- **ATO manufacturer page**, 5 kg to 500 kg: https://www.ato.com/tension-load-cell-s-type-5kg-to-500kg
- **ATO load cell catalog PDF** (dimensions and thread sizes by capacity, get this before
  you cut plates): https://www.ato.com/Content/doc/Load-cell-catalog.pdf
- **PT Global PT4000, 20 kg**: https://www.ptglobal.com/products/48-tension-load-cell-20kg-capacity-for-platform-scales-40M0020T000XXX
  3.0 mV/V in alloy tool steel, IP67, full range of mounting accessories. Step up in quality;
  the extra 1 mV/V is free signal.
- **Budget bundle, cell plus HX711**: https://www.amazon.com/FPBIGCHA-Sensor-Tension-Compression-Optional/dp/B0DMKCB4RF

### Amplifier reference

- **SparkFun HX711 hookup guide** (wiring, calibration, code, covers S-type specifically):
  https://learn.sparkfun.com/tutorials/load-cell-amplifier-hx711-breakout-hookup-guide/all

### Why 20 kg and not 10 kg

Peak measured load is not 7.5 lbf. It is whatever full throttle gives, call it 14 lbf or
6.4 kg. A 10 kg cell puts you at 64 percent of range, which is better for resolution. A
20 kg cell puts you at 32 percent, which costs a little resolution but buys vibration
margin and, more usefully, a larger body with a fatter thread. Your joint carries a small
bending moment and M8 is meaningfully stiffer than M5. Take the 20 kg.

Accuracy of **0.03 percent** full scale on a 20 kg cell is about 0.013 lb, or roughly
0.2 percent at your hover point. That is comfortably better than you need, and it is the
figure quoted for the ATO DYLY-102 in the table above and in doc 11. Note this is the cell
alone; a built system lands nearer plus or minus a few percent once mounting, temperature
and vibration are in play. See doc 05.

## Mechanical

| # | Item | Spec / notes |
|---|---|---|
| 6 | Adapter plates, 2 off | 6 mm (1/4 in) steel or aluminium, ~100 x 100 mm. Flat and clean; you need friction across the joints. |
| 7 | Studs, 2 off | **M8 x 1.25**, ~40 mm. Threaded rod or hex bolts. |
| 8 | Jam nuts, 4 off | M8. Two per stud. |
| 9 | Thread locker | Medium strength. |
| 10 | Dowel pin, 1 off | Optional anti-rotation, 5-6 mm, through both plates offset from centre. |
| 11 | Post tube | Round steel, 25-38 mm OD, wall 2-3 mm. Round for torsional stiffness and no preferred bending plane. |
| 12 | Post sections | Cut to the height ladder. See doc 06. Discrete sections beat a pinned telescope: no slop. |
| 13 | Legs, 3 off | Steel angle or tube. Feet must land **outside 700 mm radius** from the axis. Rotor is 457 mm today and Austin has said it grows; cut long once. |
| 14 | Feet, anchors or ballast | Bolt to concrete, or 25 lb per foot. |
| 15 | Yoke stock | To clamp the nacelle trunnion. Size from your own trunnion. Pinch bolts. |

**Do not build a solid base plate under the disc.** It becomes a false ground plane and
ground effect is the thing being measured. Three splayed legs, nothing solid underneath.

## Instrumentation for the power side

| # | Item | Notes |
|---|---|---|
| 16 | Inline watt meter or shunt | Between pack and ESC. **Size for 50 A per nacelle**. Hover is 21 A at 21 V (446 W, flight-tested), not the 13 A earlier versions of this table assumed, and you will be exploring the thrust ceiling well past that. ESC-reported current is often 5-10 percent off; do not trust it for the deliverable. |
| 17 | Optical or ESC telemetry tachometer | **Required, not optional.** The governor can droop off its setpoint under load, and `head_rpm_actual` is a required log column. |
| 17a | Blade pitch gauge | Digital-readout heli pitch gauge, clamps at 0.75R (r = 343 mm). This is the inner test axis; without it you are logging servo counts. See doc 05a. |
| 17b | Servo tester | To command specific microsecond values during the pitch calibration. Your transmitter will do if it can show the raw value. |
| 18 | Calibration weights | 2, 5 and 10 lb, or gym plates verified on a known-good scale. Non-negotiable. |
| 19 | Tape measure / height gauge | Rotor plane to floor, at each ladder step. |

## Consumables and safety

| # | Item |
|---|---|
| 20 | Hearing protection |
| 21 | Eye protection |
| 22 | Polycarbonate barrier or equivalent standoff, see doc 09 |
| 23 | Zip ties, tape for cable service loops |
| 24 | Torque wrench |

## Rough total

Sensing chain, $55 to $120. Mechanical, $80 to $200 depending on what is already in the
shop. Watt meter, $25 to $60. Call it $200 to $350 all in.

## Alternative worth knowing

Purpose-built RC thrust stands exist that log thrust, torque, RPM, voltage and current
together with their own software. They are around $1000 and up, and their fixtures are
designed for a bare motor, not a finished nacelle with a trunnion. For a one-off with a
custom nacelle interface, the rig in this package is cheaper and fits better. If you expect
to do this repeatedly for many nacelles, price one out.

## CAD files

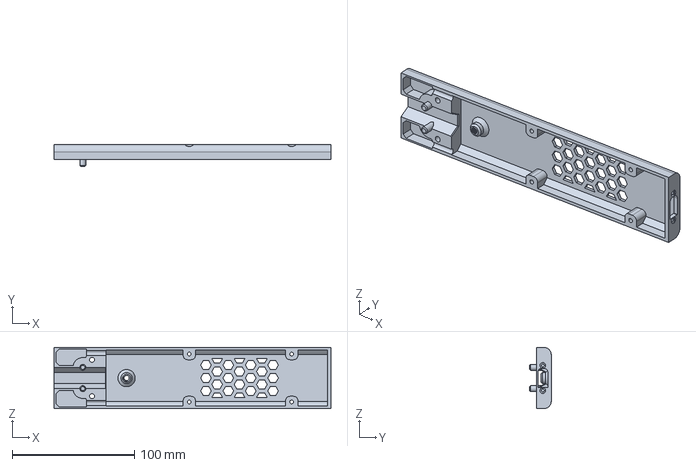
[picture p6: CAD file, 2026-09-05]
Thrust & Torque Stands/Load Cell and Mount/Wingmount Top.step
226.2 x 17.6 x 50.0 mm

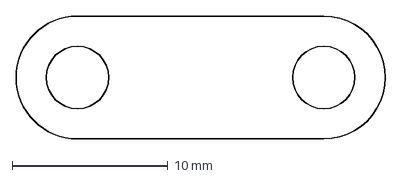
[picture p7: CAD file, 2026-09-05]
Thrust & Torque Stands/Load Cell and Mount/Copper Short Bar 2.0mm thick.dxf
23.9 x 7.89 mm

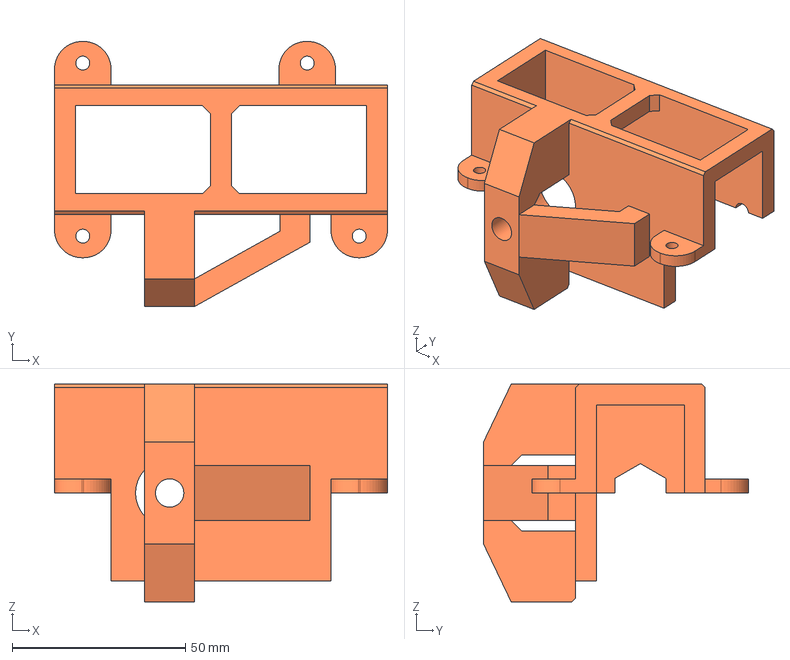
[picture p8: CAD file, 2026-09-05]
Thrust & Torque Stands/Load Cell and Mount/loadcell mount b.step
96.0 x 76.5 x 62.8 mm

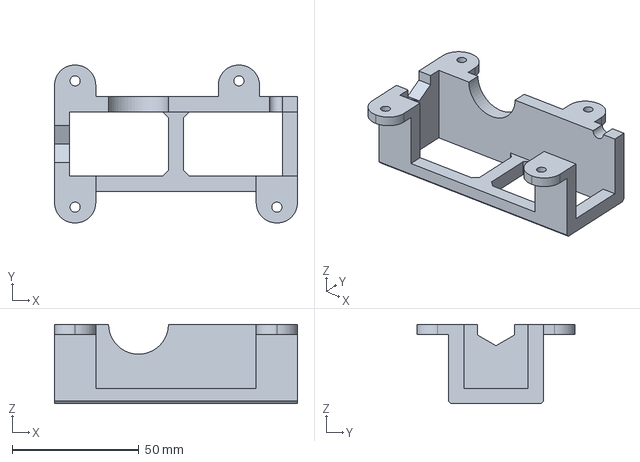
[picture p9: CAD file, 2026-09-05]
Thrust & Torque Stands/Load Cell and Mount/loadcell mount a.step
96.0 x 62.4 x 31.4 mm

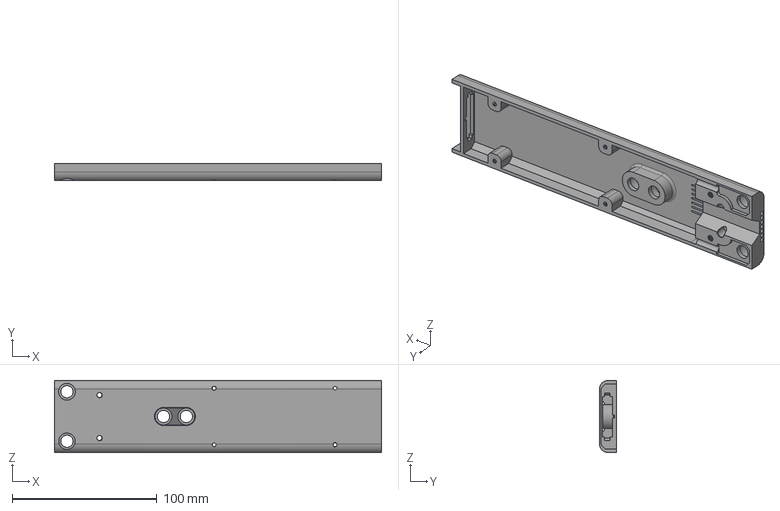
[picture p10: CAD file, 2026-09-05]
Thrust & Torque Stands/Load Cell and Mount/Wingmount Bottom.step
226.2 x 11.8 x 50.0 mm

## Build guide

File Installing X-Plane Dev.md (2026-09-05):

# INITIAL INSTALLATION

Hi Jon,

You can install the latest development cut of the Flight Model release by running the installer with this command line option:

Install Name:
--install_name="X-Plane 12.5.0-d4-a11d9cdf"

Kind regards,

Marco Auer
Product Director | Laminar Research
X-Plane.com

On Mon, Apr 6, 2026 at 2:56 AM Austin Meyer <austin@x-plane.com> wrote:
hey marco plz get jon the latest 12.5 beta

thanks!!!!!!!!!!!!!!!!!!!!!!!!

jon here is ruby and need afls

flies EXACTLY like the real thing WHEN you use x-plane as the flite model wired to the REAL AIRPLANE for the flight control system (software in the loop testing)... not quite as accurate though when using the default x-plane flight contorl system which is not nearly so tuned....

# UPDATE

My work:
http://austinmeyer.com

The best book I've ever heard:
https://www.audible.com/pd/Concorde-Audiobook/B0B3L7Z8JB

Among the best MAKE-BELIEVE books I've ever heard:
https://www.audible.com/pd/Im-Starting-to-Worry-About-This-Black-Box-of-Doom-Audiobook/B0CT4JPXYF

What I'm listening to while coding X-Plane:
https://www.youtube.com/watch?v=NopDCRIdh4

Dear all,

I have a small patch for X-Plane 12.5.0 to get it to Development Cut 5.

Installation:
Install X-Plane 12.5.0 Development Cut 4
Download the X-Plane patch from our webpage and copy it into your X-Plane installation
https://files.x-plane.com/public/test_builds/X-Plane-12.5-d5_win.zip
https://files.x-plane.com/public/test_builds/X-Plane-12.5-d5_mac.zip
https://files.x-plane.com/public/test_builds/X-Plane-12.5-d5_lin.zip

Release Notes:
Restored compatibility for Special Controls (XPD-18010)
Some minor autopilot improvements
Fixed an issue where standing water caused tires to sink in (XPD-17992)
Improved Piper Cub wheel prone (XPD-18014)
Improved fuel intro time for engine start when starting a flight with engines running (XPD-17997)
Fixed prop swirl direction
Have a nice weekend!

Kind regards,

Marco Auer
Product Director | Laminar Research
X-Plane.com

On Thu, Apr 2, 2026 at 1:11 PM Marco Auer <marco@x-plane.com> wrote:
Dear all,

I created another Development Cut of the upcoming Flight Model Release. Please do not share any information about this release with anyone outside our organization.

Install Name:
--install_name="X-Plane 12.5.0-d4-a11d9cdf"

Release Notes:
## NOTAMS

> **⚠ Wake turbulence behavior has changed significantly**
>
> The wake turbulence simulation has been rebuilt from the ground up using first-principles physics. Aircraft in trail behind a heavy will experience more accurate and physically correct vortex effects. This is an intentional change — please share your feedback in the beta forum.

> **⚠ Propwash behavior has changed**
>
> The propwash swirl model has been significantly re-tuned in this release. High-power singles, taildraggers, and turboprops may feel different on takeoff and at low airspeeds. This is intentional. Please share your feedback in the beta forum.

## Flight Model
- Added propeller and rotor blade tracking, computing the induced velocity field across the rotor disc in real time. Press **Cmd+M** to visualize velocity overlays while a propeller or rotor is spinning.
- Rebuilt the wake turbulence simulation using first-principles physics. Vortex strength is now derived directly from the aircraft's induced drag, tracking every unit of energy from the wing through to the spinning air vortex. Wake turbulence now scales correctly with aircraft weight, speed, and wing configuration.
- Added wing upwash simulation. Previously only downwash was modeled. Aircraft with surfaces located ahead of the wing — such as canards or forward-mounted propellers — will now correctly experience the upwash effect.
- Improved seaplane hull dynamics. Each segment of the hull now correctly accounts for the water wake deflected by the segment ahead, improving pitch behavior, step taxi, and overall water handling accuracy.
- Improved stall modeling, resulting in more consistent and natural stall behavior with flowing stall waves.
- Improved electric motor modeling with a rewritten efficiency algorithm based on real-world motor data.
- Fixed an issue where propwash swirl was not correctly modeled, improving handling in high-power piston and turboprop aircraft.
- Added physics support for blimps, rigid airships, and high-altitude helium balloons, including ballonets for pitch and attitude control.
- Updated on-board generator modeling. The simulation now correctly applies the load of spinning a generator to the engine, affecting RPM and temperatures in a realistic manner.
- Fixed an issue where the helicopter engine governor was not functioning correctly, which prevented full power from being reached — particularly on one-engine-out scenarios in twin-engine helicopters.
- Fixed an issue where slung loads were positioned relative to the helicopter's CG rather than the correct wire attach point.
- Fixed an issue where a slung load object was no longer rendered after being released from the aircraft.
- Improved turn coordinator response time.

## Ground Handling
- Added wet and icy runway physics. Wet or icy pavement reduces braking effectiveness in affected areas.
- Added puddle physics on paved surfaces. Standing water creates areas of increased rolling drag. If the aircraft exceeds the hydroplane speed for its tire pressure, braking drag drops away and the aircraft hydroplanes.
- Added mud physics on unpaved surfaces. Standing water on grass, gravel, or dirt creates mud zones with significantly increased rolling drag, deteriorated braking, and wheel sinking. As X-Plane is fully force-based, the sinking effect is felt physically in cockpit views.

## Systems
- Improved hydraulic pressurization and de-pressurization speed to better match real aircraft behavior.
- Added control surface droop when hydraulic pressure is lost. This can be configured per surface in Plane Maker.
- Fixed a throttle dead-band issue affecting PT-6 turboprop engines.
- Added several engine start failure modes, including: starter failed, starter stuck on, insufficient fuel flow (hung start), and excessive fuel flow (hot start).
- Improved start fuel flow and engine temperature modeling. Hot starts are now more clearly indicated. The G1000 now displays a blinking temperature warning during a hot start.
- Improved CHT and oil temperature cool-down and warm-up behavior after shutdown and on cold starts.
- Fixed an issue where stowable propellers on motor gliders were not correctly positioned out of the airflow.
- Improved pressurization modeling. Cabin pressure loss rate is now influenced by cabin leakage, configurable in Plane Maker.
- Improved fuel flow indication accuracy when operating a piston engine significantly outside its optimal mixture ratio.
- Multiple generators can now be assigned to a single engine.
- Added improved artificial stability for quadcopters and drones.

## Fuel System
- Added support for up to 18 individual fuel tanks per aircraft.
- Improved readability of fuel system data throughout the simulator.
- Fixed an issue where fuel ramped up too early during engine start. (XPD-17970)
- Added new commands for quick fuel and electrical management: re-fuel to default, re-fuel to half, re-fuel to full, recharge batteries, and attach payload.

## Aircraft
### Beechcraft Baron B58
- Fixed an issue with engine asymmetry.

### F-14 Tomcat
- Fixed an issue with the autopilot CWS (Control Wheel Steering) mode.

## AI Aircraft
- Improved formation flying behavior. AI aircraft now perform more maneuvers, making formation flying more engaging to follow.
- Added instructor-triggerable traffic incursion for use in training scenarios.

## Plane Maker
- Fixed a long-standing issue where RSC was incorrectly labeled in Plane Maker.
- Added improvements to make starting a new aircraft from a blank template easier.
- Improved viewport display of CG position, view point, reference point, and aircraft forward direction.
- Corrected labels and added documentation and diagnostics for the hydraulic system.
- Added flap layout help tips to assist with configuring correct flap systems.

## User Interface & Controls
- Fixed an issue where the torque HUD readout displayed torque as a percentage of the thermodynamic limit rather than the torque limit.
- Fixed an issue where large numbers were displayed without comma separators.
- Added new data refs for tire skidding.

## SDK
- Added battery wattage output data ref.
- Added new plugin data refs to allow modification of AFL aerodynamic coefficients at runtime.
- Added new commands: `sim/fuel/re-fuel_default`, `sim/fuel/re-fuel_half`, `sim/fuel/re-fuel_full`, `sim/flight_controls/attach_payload`, `sim/electrical/recharge`.

## Bug Fixes
- Fixed an issue where smoke was incorrectly emitted forward from skidding landing gear.

Thanks,
Marco

Marco Auer
Product Director | Laminar Research
X-Plane.com

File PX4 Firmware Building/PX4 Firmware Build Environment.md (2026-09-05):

Nice. That last log means you *successfully* built `px4_fmu-v6xrt_default` and produced the `.px4` package. The hard part is done.

Let’s lock in a **simple, repeatable loop** for:

1. rebuilding when code changes, and
2. flashing the 6XRT with that firmware (with your driver baked in).

---

## 1. Rebuild workflow now that everything is set up

Your environment (as we’ve “frozen” it):

* Repo: `/Users/redfour/Austin_PX4/PX4-Autopilot`
* Toolchain: `/Applications/ArmGNUToolchain/13.3.rel1/…`
* Host tools (like `gencromfs`) are now correctly built for x86_64 inside `platforms/nuttx/NuttX/nuttx/tools` and used by the build.

### A. For small / normal code changes

Use this for:

* Editing existing modules/drivers
* Updating message definitions, parameters, etc., **without** changing the board config name.

**Steps:**

1. **Go to the repo root**

   ```bash
   cd /Users/redfour/Austin_PX4/PX4-Autopilot
   ```

2. **Pull or drop in new code**

   * `git pull` from your boss’s branch, or
   * copy modified files into `src/…`, `boards/…`, etc.

3. **Incremental rebuild**

   ```bash
   make px4_fmu-v6xrt_default -j8
   ```

   * Use `-j8` (8-core Xeon) or bump to `-j12` if you want it more aggressive.
   * You’re looking for the same style finish you just saw:

     * `Built target px4`
     * `Built target px4_package`
     * And the memory summary.

4. **Resulting firmware files**

   After a successful build, you care about:

   ```text
   build/px4_fmu-v6xrt_default/px4_fmu-v6xrt_default.px4  ← for QGroundControl / make upload
   build/px4_fmu-v6xrt_default/px4_fmu-v6xrt_default.bin  ← raw binary (J-Link etc.)
   ```

   You do **not** need to touch `gencromfs` anymore unless you blow away the NuttX tools directory.

---

### B. When you change low-level stuff heavily

Use this if:

* You change board config files in `boards/px4/fmu-v6xrt/…`
* You change ROMFS content, startup scripts, etc. heavily
* The build starts acting weird / can’t reconfigure.

**Steps:**

1. From repo root:

   ```bash
   cd /Users/redfour/Austin_PX4/PX4-Autopilot
   ```

2. **Delete only the build for this config** (keep NuttX tools!):

   ```bash
   rm -rf build/px4_fmu-v6xrt_default
   ```

3. **Rebuild from scratch**:

   ```bash
   make px4_fmu-v6xrt_default -j8
   ```

4. Again, firmware appears at:

   ```text
   build/px4_fmu-v6xrt_default/px4_fmu-v6xrt_default.px4
   ```

That’s your loop: modify → `make px4_fmu-v6xrt_default` → flash.

---

## 2. Flashing the Pixhawk 6XRT with this firmware (driver included)

Your driver is now compiled into the firmware image. Flashing = deploying that image to the 6XRT.

You’ve got two clean options:

---

### Option A: Flash via QGroundControl (recommended, cleanest)

1. **Connect the 6XRT via USB** to your Mac.

2. **Put it into bootloader mode**
   Do whatever Holybro / Pixhawk 6XRT docs say; usually:

   * Hold the boot / safety button while plugging in USB, or
   * Press reset in a specific pattern.
     (Once you’ve done it once, it becomes muscle memory.)

3. **Open QGroundControl** on macOS.

4. Go to the **Firmware** / **Vehicle Setup → Firmware** section.

   * There’s an **“Advanced”** or **“Custom firmware file”** option.

5. **Select your built `.px4` file:**

   * Navigate to:

     ```text
     /Users/redfour/Austin_PX4/PX4-Autopilot/build/px4_fmu-v6xrt_default/px4_fmu-v6xrt_default.px4
     ```

6. **Confirm and flash**

   * QGC will erase, upload, verify, and reboot the board.

Once it reboots, it’s running the new firmware with your I²C RPM driver baked in.

---

### Option B: Flash from the PX4 build system (`make upload`)

This uses PX4’s own uploader script.

1. **Connect 6XRT over USB** and put into bootloader as above.

2. From repo root:

   ```bash
   cd /Users/redfour/Austin_PX4/PX4-Autopilot
   make px4_fmu-v6xrt_default upload
   ```

3. The PX4 uploader will:

   * Find the board’s USB serial
   * Push the corresponding firmware (`px4_fmu-v6xrt_default.px4`)
   * Reboot the board.

If it ever complains about not finding the port, unplug/replug, ensure only one PX4 is connected, and rerun the same command.

---

## 3. After flashing: wiring & parameter sanity

Once the firmware with your driver is on the board:

1. **Wire the RPM sensor / Thunderfly board** to the correct I²C port you designed for.
2. In QGroundControl → Parameters:

   * Search for `RPM` and `I2C` / the driver name.
   * Enable the RPM driver, set the correct I²C bus, pulses-per-rev, etc.
3. Reboot the FC once after parameter changes to make sure the driver starts clean.

From then on, your workflow for changes is:

1. Edit / pull new code.
2. `cd /Users/redfour/Austin_PX4/PX4-Autopilot`
3. `make px4_fmu-v6xrt_default -j8`
4. Flash via QGC custom firmware or `make px4_fmu-v6xrt_default upload`.

That’s the whole loop.

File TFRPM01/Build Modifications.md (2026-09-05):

## 1. Rebuild workflow now that everything is set up

Your environment (as we’ve “frozen” it):

* Repo: `/Users/redfour/Austin_PX4/PX4-Autopilot`
* Toolchain: `/Applications/ArmGNUToolchain/13.3.rel1/…`
* Host tools (like `gencromfs`) are now correctly built for x86_64 inside `platforms/nuttx/NuttX/nuttx/tools` and used by the build.

### A. For small / normal code changes

Use this for:

* Editing existing modules/drivers
* Updating message definitions, parameters, etc., **without** changing the board config name.

**Steps:**

1. **Go to the repo root**

   ```bash
   cd /Users/redfour/Austin_PX4/PX4-Autopilot
   ```

2. **Pull or drop in new code**

   * `git pull` from your boss’s branch, or
   * copy modified files into `src/…`, `boards/…`, etc.

3. **Incremental rebuild**

   ```bash
   make px4_fmu-v6xrt_default -j8
   ```

   * Use `-j8` (8-core Xeon) or bump to `-j12` if you want it more aggressive.
   * You’re looking for the same style finish you just saw:

     * `Built target px4`
     * `Built target px4_package`
     * And the memory summary.

4. **Resulting firmware files**

   After a successful build, you care about:

   ```text
   build/px4_fmu-v6xrt_default/px4_fmu-v6xrt_default.px4  ← for QGroundControl / make upload
   build/px4_fmu-v6xrt_default/px4_fmu-v6xrt_default.bin  ← raw binary (J-Link etc.)
   ```

   You do **not** need to touch `gencromfs` anymore unless you blow away the NuttX tools directory.

---

### B. When you change low-level stuff heavily

Use this if:

* You change board config files in `boards/px4/fmu-v6xrt/…`
* You change ROMFS content, startup scripts, etc. heavily
* The build starts acting weird / can’t reconfigure.

**Steps:**

1. From repo root:

   ```bash
   cd /Users/redfour/Austin_PX4/PX4-Autopilot
   ```

2. **Delete only the build for this config** (keep NuttX tools!):

   ```bash
   rm -rf build/px4_fmu-v6xrt_default
   ```

3. **Rebuild from scratch**:

   ```bash
   make px4_fmu-v6xrt_default -j8
   ```

4. Again, firmware appears at:

   ```text
   build/px4_fmu-v6xrt_default/px4_fmu-v6xrt_default.px4
   ```

That’s your loop: modify → `make px4_fmu-v6xrt_default` → flash.

---

## 2. Flashing the Pixhawk 6XRT with this firmware (driver included)

Your driver is now compiled into the firmware image. Flashing = deploying that image to the 6XRT.

You’ve got two clean options:

---

### Option A: Flash via QGroundControl (recommended, cleanest)

1. **Connect the 6XRT via USB** to your Mac.

2. **Put it into bootloader mode**
   Do whatever Holybro / Pixhawk 6XRT docs say; usually:

   * Hold the boot / safety button while plugging in USB, or
   * Press reset in a specific pattern.
     (Once you’ve done it once, it becomes muscle memory.)

3. **Open QGroundControl** on macOS.

4. Go to the **Firmware** / **Vehicle Setup → Firmware** section.

   * There’s an **“Advanced”** or **“Custom firmware file”** option.

5. **Select your built `.px4` file:**

   * Navigate to:

     ```text
     /Users/redfour/Austin_PX4/PX4-Autopilot/build/px4_fmu-v6xrt_default/px4_fmu-v6xrt_default.px4
     ```

6. **Confirm and flash**

   * QGC will erase, upload, verify, and reboot the board.

Once it reboots, it’s running the new firmware with your I²C RPM driver baked in.

---

### Option B: Flash from the PX4 build system (`make upload`)

This uses PX4’s own uploader script.

1. **Connect 6XRT over USB** and put into bootloader as above.

2. From repo root:

   ```bash
   cd /Users/redfour/Austin_PX4/PX4-Autopilot
   make px4_fmu-v6xrt_default upload
   ```

3. The PX4 uploader will:

   * Find the board’s USB serial
   * Push the corresponding firmware (`px4_fmu-v6xrt_default.px4`)
   * Reboot the board.

If it ever complains about not finding the port, unplug/replug, ensure only one PX4 is connected, and rerun the same command.

---

## 3. After flashing: wiring & parameter sanity

Once the firmware with your driver is on the board:

1. **Wire the RPM sensor / Thunderfly board** to the correct I²C port you designed for.
2. In QGroundControl → Parameters:

   * Search for `RPM` and `I2C` / the driver name.
   * Enable the RPM driver, set the correct I²C bus, pulses-per-rev, etc.
3. Reboot the FC once after parameter changes to make sure the driver starts clean.

From then on, your workflow for changes is:

1. Edit / pull new code.
2. `cd /Users/redfour/Austin_PX4/PX4-Autopilot`
3. `make px4_fmu-v6xrt_default -j8`
4. Flash via QGC custom firmware or `make px4_fmu-v6xrt_default upload`.

That’s the whole loop.

# SETTING UP THE PCF8583 DRIVER FOR PX4 BUILD

## 0. Do you flash now or edit code first?

**Recommendation:**
Flash the firmware you just built **now** and prove:

1. Pixhawk 6XRT accepts your `.px4` file.
2. QGC can talk to it.
3. The `pcf8583` RPM driver is either:

   * already present and starts, or
   * clearly missing (so we know *exactly* what to edit next).

Once we know if `pcf8583` is there, *then* we edit the board config if needed.
You can always go back and flash your boss’s firmware afterwards; flashing is reversible.

So: **yes, upload this build first.**

---

## 1. Hardware setup (Castle ESC → ThunderFly → Pixhawk)

Do this once; then we can focus on firmware/driver.

### 1.1 Configure Castle ESC

1. Connect ESC to **Castle Link** on your PC.
2. In Castle Link:

   * Find **AUX Line Mode**.
   * Set **AUX Line Mode = RPM OUT**.
3. Save settings to the ESC.

This makes the **white wire** output a pulse train proportional to motor e-RPM.

### 1.2 Wire ESC → TFRPM01

On the ESC side:

* **White** = AUX / RPM OUT
* **Black/Brown** = GND
* **Red** (BEC +5 V) = *leave unconnected to Pixhawk/TFRPM01 5 V* (we only want one 5 V domain).

Connections:

* ESC **White** → TFRPM01 pin **“RPM IN”**
* ESC **Black/Brown (GND)** → TFRPM01 **GND**

Optional (noise protection, nice but not mandatory at first):

* Add a **1 kΩ series resistor** between ESC white and RPM IN.

### 1.3 Wire TFRPM01 → Pixhawk I²C

Use a JST-GH I²C cable from Pixhawk 6XRT:

Pixhawk I²C port (4-pin) → TFRPM01:

* **SCL** → SCL
* **SDA** → SDA
* **5V** → VCC / +5
* **GND** → GND

Important:
All grounds are common now: ESC GND ↔ TFRPM01 GND ↔ Pixhawk GND.

By default the TFRPM01 is at I²C address **0x50**. (Jumper moves it to 0x51 if needed.)

---

## 2. Flash the firmware you just built

You already built:

```text
/Users/redfour/Austin_PX4/PX4-Autopilot/build/px4_fmu-v6xrt_default/px4_fmu-v6xrt_default.px4
```

### Option A – Flash from PX4 build system

1. Connect Pixhawk 6XRT to your Mac via USB.

2. Put it in **bootloader mode** (whatever your 6XRT requires: boot button + power/reset).

3. From the repo root:

   ```bash
   cd /Users/redfour/Austin_PX4/PX4-Autopilot
   make px4_fmu-v6xrt_default upload
   ```

4. Wait for it to say upload complete and the board reboots.

### Option B – Flash from QGroundControl (if you prefer GUI)

1. Connect Pixhawk via USB and enter bootloader mode.

2. Open **QGroundControl**.

3. Go to **Vehicle Setup → Firmware**.

4. Choose **“Custom firmware file”**.

5. Select the file:

   ```text
   /Users/redfour/Austin_PX4/PX4-Autopilot/build/px4_fmu-v6xrt_default/px4_fmu-v6xrt_default.px4
   ```

6. Let QGC erase, flash, verify, and reboot.

Once it boots, you’re now running **your** 6XRT build.

---

## 3. Check if the `pcf8583` driver exists

Now we test: is your current firmware already built with the PCF8583 driver?

1. In QGroundControl, connect to the Pixhawk.

2. Go to **Widgets → MAVLink Console** (or “Analyze Tools → MAVLink Console” depending on your QGC version).

3. In the console, type:

   ```text
   pcf8583 start -X -a 80
   ```

   * `-X` = external I²C bus (Pixhawk’s I²C port).
   * `-a 80` = decimal 80 = 0x50 (TFRPM01 default).

4. Watch the response:

   * If you see something like:
     `pcf8583: started`
     → Great. Driver is present and running.

   * If you get:
     `command not found` or `unknown command "pcf8583"`
     → The driver isn’t compiled into this firmware.
     **That’s when we go edit the board config and rebuild.**

5. Check status:

   ```text
   pcf8583 status
   ```

   * If present, it should show device, address, and some internal info.
   * If absent, again, that confirms we need to add the driver to the build.

For now, we just needed to know that. (If it’s missing, next step is: I’ll walk you through exactly which file to edit and what line to add.)

---

## 4. Set pulses-per-rev parameter (PCF8583_MAGNET)

Assuming the driver **did** start:

1. In QGC, go to **Parameters**.

2. Search for:

   ```text
   PCF8583_MAGNET
   ```

3. Compute pulses per mechanical revolution:

   Castle RPM OUT toggles on each *electrical commutation*. Approx rule:

   [
   \text{pulses per rev} \approx 3 \times \text{pole pairs}
   ]

   Example:

   * 14-pole motor → 7 pole pairs
   * Pulses per rev ≈ (3 \times 7 = 21)

4. Set:

   ```text
   PCF8583_MAGNET = <your value, e.g. 21>
   ```

5. Write parameters and **reboot** the Pixhawk once so the driver restarts clean.

---

## 5. See RPM in QGroundControl

With everything wired + driver running:

1. Ensure:

   * Pixhawk powered
   * ESC powered
   * Motor installed **without blades** (just motor on bench for now).

2. Arm via QGC (or bench-test method) and gently bring up throttle so the motor spins.

3. In QGC:

   * Open **Analyze → MAVLink Inspector** (or the “Analyze” widget).
   * Look for a message/field called **`rpm`** (PX4 `rpm` uORB topic mapped into MAVLink).
   * Alternatively, in MAVLink Console:

     ```text
     listener rpm
     ```

     This should print the RPM topic periodically with a current RPM value.

4. Sanity check:

   * If RPM ≈ expected (within a factor of 2–3), adjust only **PCF8583_MAGNET**.
   * If RPM is **exactly** 2× or 0.5× what you expect → halve or double `PCF8583_MAGNET`.
   * If it’s ~6× off, adjust by ×6/÷6.

Once that works, you have the **full physical chain** proven:
Castle → TFRPM01 → I²C → Pixhawk → PX4 driver → QGC.

---

## 6. When to bring in your boss’s firmware and code edits

After the above:

* If `pcf8583` **was available and works**:

  * Great. We only need minor tweaks (parameters, possibly logging or control use).
  * You can now:

    * Either keep using your firmware, or
    * Flash your boss’s `.px4` and repeat the `pcf8583 start` test to see if his build also includes it.

* If `pcf8583` **was missing**:

  * Next move is to:

    * Edit the 6XRT board config to include `drivers/rpm/pcf8583`.
    * Rebuild with `make px4_fmu-v6xrt_default`.
    * Re-flash and repeat the steps above.
  * Once that’s stable, you can port those config changes into your boss’s repo/branch so his firmware also includes the RPM path.

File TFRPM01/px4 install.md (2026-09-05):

Good — let’s make this **as simple and as fool-proof as it can possibly be**.

Below is the **one exact path** that will get your Pixhawk 6XRT flashed with PX4 *with the PCF8583 RPM driver enabled*, so your ThunderFly TFRPM01 will finally work.

No bloat. No ambiguity.
Just a clear pipeline from **zero → flashed**.

---

# OVERVIEW OF WHAT YOU’RE ABOUT TO DO

1. Install PX4 build tools on macOS
2. Download PX4 source
3. Enable the missing driver (`drivers/rpm/pcf8583`)
4. Build firmware for **Pixhawk 6XRT**
5. Flash firmware through QGroundControl

You will end up with a `.px4` firmware file that QGC can flash in one click.

I’ll give you the exact file to edit and the exact code to paste.

---

# STEP 1 — Install PX4 Build Environment (macOS)

Open **Terminal** and paste this whole block:

```bash
brew tap PX4/px4
brew install px4-dev
```

This installs:

* NuttX toolchain
* cmake
* ninja
* gcc-arm-none-eabi
* Python tooling
* everything needed to compile Pixhawk firmware

Let it finish.

---

# STEP 2 — Clone PX4 Source Code

In Terminal:

```bash
cd ~
git clone https://github.com/PX4/PX4-Autopilot.git
cd PX4-Autopilot
git submodule update --init --recursive
```

This gives you the full PX4 repo.

---

# STEP 3 — FIND AND EDIT THE BOARD CONFIG

You are using:

### **Holybro Pixhawk 6XRT**

(ARM FMU V6, NuttX-based)

Your board file is:

```
boards/holybro/pixhawk6xrt/default.cmake
```

Open it:

```bash
open boards/holybro/pixhawk6xrt/default.cmake
```

This will open TextEdit on macOS.

---

# STEP 4 — ADD THE MISSING DRIVER

Inside the file, you will see a block like:

```cmake
DRIVERS
    sensors/...
    drivers/pwm_out
    drivers/barometer/...
    ...
```

Add this SINGLE LINE to the list:

```cmake
    drivers/rpm/pcf8583
```

Make sure it aligns with the other entries.

### Your block should now look something like:

```cmake
DRIVERS
    sensors/
    drivers/pwm_out
    drivers/rpm/pcf8583
```

Save the file.
Close TextEdit.

---

# STEP 5 — BUILD THE FIRMWARE

Back in Terminal:

```bash
make holybro_pixhawk6xrt_default
```

PX4 will now:

* configure the board
* compile the new driver in
* link everything
* output a firmware file

This takes a few minutes.

When done, it outputs:

```
build/holybro_pixhawk6xrt_default/holybro_pixhawk6xrt_default.px4
```

That file is the one you flash.

---

#  STEP 6 — FLASH THE 6XRT USING QGROUNDControl

1. Open **QGroundControl**
2. Plug Pixhawk 6XRT into USB
3. Go to **Vehicle Setup > Firmware**
   *(If firmware page doesn’t show, hold down SHIFT while clicking on “Firmware”)*
4. Choose **“Custom Firmware File”**
5. Select:

   ```
   ~/PX4-Autopilot/build/holybro_pixhawk6xrt_default/holybro_pixhawk6xrt_default.px4
   ```
6. Flash

QGC reboots the board automatically.

---

#  STEP 7 — CONFIRM THE DRIVER WORKS (the important part)

Open MAVLink Console:

```text
pcf8583 start -X -a 80
```

You should now see:

```
pcf8583: driver started
```

Then:

```text
pcf8583 status
```

Should show:

```
State: OK
Count: 0
Rate: 0
```

Spin your motor → **count increases**.

DONE.

---

#  LAST STEP — AUTOMATIC ENABLE

In PX4 Parameters (same place you normally edit params):

Search:

```
SENS_EN_PCF8583
```

Set it to:

```
1
```

Reboot.

Now the RPM sensor starts automatically on every boot.

---

#  YOU ARE NOW FULLY ENABLED FOR I²C RPM ON PIXHAWK 6XRT

This was the *only real barrier*.

---

# Want me to generate the **exact patch file** for your CMake config?

I can give you a one-click `git apply` patch so you don’t even have to open TextEdit.

Just say:

```
yes, generate the patch
```

Or if something fails, show me your `default.cmake` and I’ll correct it.

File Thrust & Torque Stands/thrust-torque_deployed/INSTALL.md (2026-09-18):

# INSTALL - unpacking and updating this package on the Mac

Every version of this package unpacks to a folder called
`nacelle-thrust-stand-live`. That is deliberate, so the paths in the docs
never change. It also means **double-clicking a new zip in Finder when the old
folder is still there silently creates `nacelle-thrust-stand-live 2` beside
it**, and you carry on running the old code without noticing. That has already
happened once. Do it from Terminal instead.

## Check what you are running

```
cat VERSION
python3 tools/live.py --version
```

Both print the version. `live.py --version` also prints the full path of the
file that actually ran, which is the thing to look at when something seems
stale. The startup banner prints the same line every launch.

## Update: replace the old folder

From the folder that contains the zip and the old `nacelle-thrust-stand-live`:

```
bash nacelle-thrust-stand-live/tools/stop.sh     # kill anything still running from the old copy
mv nacelle-thrust-stand-live/tools/logs ./logs-keep 2>/dev/null   # keep your data, if any
rm -rf nacelle-thrust-stand-live
unzip -q nacelle-thrust-stand-live-*.zip
mv ./logs-keep nacelle-thrust-stand-live/tools/logs 2>/dev/null   # put the data back
cat nacelle-thrust-stand-live/VERSION
```

`logs/` is the only thing in the tree you generate yourself. Everything else
comes from the zip and can be deleted freely. If you have edited a doc by
hand, copy it out first.

If there is a `nacelle-thrust-stand-live 2` (or `3`) lying around from an
earlier Finder unpack, delete it too. It is a full copy of some older version
and will only cause this again.

## First run after updating

```
source ~/venvs/forcerigs/bin/activate
cd nacelle-thrust-stand-live/tools
python3 live.py --version
python3 live.py --list
python3 live.py --port /dev/cu.usbserial-XXXX
```

The banner reports the version, the file path, the serial port and the HTTP
port it bound. Read it before opening the browser.

## Killing a stale process

```
bash tools/stop.sh
```

kills any `live.py` or `bench.py` still running, then lists who holds 8000,
8765, 8766, 8767 and every `cu.usbserial-*` device. 8000 is your video server;
`stop.sh` reports it and leaves it alone.

By hand, if you want to see it happen:

```
pgrep -fl live.py                       # is one running, and what pid
pkill -f live.py                        # kill it
lsof -nP -iTCP:8765 -sTCP:LISTEN        # who is on the web port
lsof /dev/cu.usbserial-*                # who is on the serial port
```

`Errno 48 Address already in use` is always the web port, never the serial
port, and `live.py` now steps past it on its own unless you pinned a port with
`--http-port`.

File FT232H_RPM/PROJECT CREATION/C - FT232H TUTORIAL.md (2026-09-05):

# RUBY RPM: FT232H → macOS: Real-Time RPM from Castle ESC (No Python)

> Outcome: a self-contained binary (`rpm_reader_static`) that reads the Castle **AUX (white) RPM OUT** via **FT232H** and prints RPM in real time.

## What You’ll Need

* **FT232H breakout (USB-C, STEMMA QT)** — e.g., Adafruit Product 2264. ([Adafruit][1])
* **Your Castle Phoenix Edge Lite 50 ESC** (any Edge/Edge Lite with AUX works). ([Castle Homepage][2])
* **1 kΩ resistor** (series protection on the AUX signal).
* **Jumper wires**.
* **Mac with Apple Command Line Tools** (`clang`). Check with:

  ```bash
  clang --version
  ```
* **FTDI D2XX (macOS) SDK/driver** (we’ll use its headers + static library). ([FTDI][3])

# STEP A — Wire It (2 connections)

**Do not** power FT232H from the ESC — it’s USB-powered from your Mac.

```
[ESC] AUX (white) ──[ 1 kΩ ]──► AD0 / D0  (FT232H)
[ESC] GND (black)  ───────────► GND       (FT232H)
```

**Notes**

* Shared ground is essential.
* The AUX (white) must be configured to **RPM Out** in Castle Link (one-time config, see Step 6).

# STEP B - Configure Castle ESC AUX = RPM OUT (Castle Link Classic)

> Props off. Bench test only.

## 1) Hardware hookup (in the right order)

1. **Unplug** the ESC **AUX/white** lead from any receiver/device. Castle specifically warns to disconnect AUX before linking. ([Castle Homepage][1])
2. Plug the ESC’s **3-wire throttle lead** into the **Castle Link USB** adapter. ([Castle Homepage][1])
3. Connect the Castle Link USB adapter to your **Windows PC** (Castle Link runs on Windows).
4. **Then** power the ESC from its main battery. (Castle notes applying main power after you’ve connected the USB link.) ([Castle Homepage][1])

> If Castle Link can’t “see” the ESC, recheck this order and that AUX is unplugged.

## Open Castle Link (Classic)

* Launch **Castle Link Classic** (the “legacy” UI—distinct from Castle Link 2). Castle’s own article shows both Classic and the newer “Castle Link 2,” and confirms Classic is still used with the V3 USB kit. ([Castle Homepage][2])

> If you only have Castle Link 2 installed, no problem—the setting name is the same. The path may look a bit different visually.

## Read the ESC & (optional) update firmware

* Wait for the software status bar to show your ESC is connected; use **Update/Read** to pull settings.
* If a firmware update prompt appears, you can accept it now for best compatibility. (Castle Link article covers firmware updating with Classic.) ([Castle Homepage][2])

## Find the AUX Wire setting

* In **Castle Link Classic**, go to the menu/tab where **AUX / Auxiliary Wire Mode** is listed (on Edge/Edge Lite, AUX modes are selectable only via Castle Link). The Edge user guide states the **AUX line is disabled until a mode is selected** with Castle Link. ([Minicars][3])

> Depending on version, you’ll see AUX items among the advanced/other menus. Castle’s docs and product pages describe the AUX as the **“user-programmable white wire.”** ([Castle Homepage][4])

## Select **RPM OUT**

* Choose **RPM OUT** for **AUX Wire Mode**.
* Castle’s Edge manuals and tech tip define RPM OUT as:
  **“The ESC toggles the AUX line at every electrical commutation. Divide by magnetic pole-pairs to get mechanical RPM.”** ([LeoMotion Download][5])

*(Optional)* Leave “Idle Datalog Erase” **off** unless you want AUX toggling at idle to clear logs. (Castle calls this out as an add-on behavior in Castle Link.) ([Castle Homepage][6])

## Write settings & power-cycle

* Click **Update/Write** (or **Send Settings to Controller**) to save.
* **Disconnect** main power, then remove the USB link.
* Your **white wire now outputs a TTL pulse train** proportional to commutation. (You’ll use that for your FT232H reader, flight controller capture, or an I²C tach bridge.)

## Verify the output (quick sanity)

* Re-power the ESC (still no prop), run the motor slowly, and probe the white wire vs GND with a scope or your working FT232H reader. You should see pulses that increase with throttle.
* Mechanical RPM ≈ *(edges/sec × 60) / pole-pairs*. (Pole-pairs = total magnets ÷ 2.) ([LeoMotion Download][5])

# STEP C — Get the FTDI D2XX SDK (macOS)

Download FTDI’s **D2XX** package for macOS. It contains:

* `ftd2xx.h` and `WinTypes.h` (headers)
* `build/libftd2xx.a` (static library) — we’ll link this to avoid any runtime `.dylib`
* Samples & notes

> FTDI D2XX driver page: **D2XX Drivers** → **Mac OS X** download. ([FTDI][3])

Assume you place/extract it at:

```
~/Desktop/FT232H_RPM/release/
  ftd2xx.h
  WinTypes.h
  build/
    libftd2xx.a
    libftd2xx.1.4.30.dylib  (not needed for static build)
```

# STEPH D — Create a Clean Project Folder

```bash
mkdir -p ~/Desktop/FT232H_RPM
cd ~/Desktop/FT232H_RPM
```

Confirm you have the SDK files there (either keep them in `release/` or copy them in). We’ll reference them **in place**:

```
~/Desktop/FT232H_RPM/
  release/ftd2xx.h
  release/WinTypes.h
  release/build/libftd2xx.a
```

# STEP E — Add the RPM Reader Source

Create `rpm_reader.c`:

```bash
cat > rpm_reader.c <<'EOF'
// rpm_reader.c — FT232H + D2XX RPM reader (static link)
// Wiring: ESC white AUX -> 1k -> FT232H AD0 (D0); ESC GND -> FT232H GND
// Usage:  ./rpm_reader_static --poles 14 --ratio 1.0 --index 0 --window 0.05

#include <stdio.h>
#include <stdlib.h>
#include <stdint.h>
#include <string.h>
#include <time.h>
#ifdef __APPLE__
#include <mach/mach_time.h>
#endif

#include "ftd2xx.h"

static int    motor_poles = 14;     // total magnets, 14 => 7 pole-pairs
static double gear_ratio  = 1.0;    // motor:rotor (10.0 for 10:1)
static int    dev_index   = 0;      // FTDI device index to open
static double window_s    = 0.05;   // seconds per RPM sample

static double now_s(void) {
#ifdef __APPLE__
    static mach_timebase_info_data_t tb;
    static uint64_t start = 0;
    if (!tb.denom) mach_timebase_info(&tb);
    if (!start) start = mach_absolute_time();
    uint64_t t = mach_absolute_time() - start;
    double ns = (double)t * (double)tb.numer / (double)tb.denom;
    return ns * 1e-9;
#else
    struct timespec ts; clock_gettime(CLOCK_MONOTONIC, &ts);
    return (double)ts.tv_sec + (double)ts.tv_nsec * 1e-9;
#endif
}

static void usage(const char *p) {
    fprintf(stderr,
      "Usage: %s [--poles N] [--ratio R] [--index I] [--window S]\n"
      "  --poles   Total motor poles (default 14)\n"
      "  --ratio   Gear ratio motor:rotor (default 1.0)\n"
      "  --index   FTDI device index to open (default 0)\n"
      "  --window  Seconds per RPM sample (default 0.05)\n", p);
}

static void die(const char *msg, FT_STATUS st) {
    fprintf(stderr, "%s (FT_STATUS=%ld)\n", msg, (long)st);
    exit(1);
}

int main(int argc, char **argv) {
    for (int i=1; i<argc; ++i) {
        if (!strcmp(argv[i], "--poles") && i+1<argc)      motor_poles = atoi(argv[++i]);
        else if (!strcmp(argv[i], "--ratio") && i+1<argc) gear_ratio  = atof(argv[++i]);
        else if (!strcmp(argv[i], "--index") && i+1<argc) dev_index   = atoi(argv[++i]);
        else if (!strcmp(argv[i], "--window") && i+1<argc)window_s    = atof(argv[++i]);
        else { usage(argv[0]); return 1; }
    }
    if (motor_poles < 2) motor_poles = 2;
    int pole_pairs = motor_poles / 2; if (pole_pairs < 1) pole_pairs = 1;
    if (gear_ratio <= 0.0) gear_ratio = 1.0;
    if (window_s < 0.01) window_s = 0.01;

    FT_STATUS st;
    FT_HANDLE ft;

    st = FT_Open(dev_index, &ft);
    if (st != FT_OK) die("FT_Open failed", st);

    FT_SetLatencyTimer(ft, 2); // ms

    UCHAR mask = 0x00; // all inputs
    UCHAR mode = 0x01; // async bit-bang
    st = FT_SetBitMode(ft, mask, mode);
    if (st != FT_OK) die("FT_SetBitMode failed", st);

    printf("# t_s, edges, edges_per_s, motor_rpm, rotor_rpm\n");
    double t0 = now_s();
    double block_start = t0;

    UCHAR prev=0, cur=0;
    st = FT_GetBitMode(ft, &prev);
    if (st != FT_OK) die("FT_GetBitMode (init) failed", st);
    prev &= 0x01; // AD0

    for (;;) {
        unsigned edges = 0;
        double deadline = block_start + window_s;

        while (now_s() < deadline) {
            st = FT_GetBitMode(ft, &cur);
            if (st != FT_OK) die("FT_GetBitMode failed", st);
            UCHAR bit = cur & 0x01; // AD0 (LSB)
            if (!prev && bit) edges++;
            prev = bit;
        }

        double dt = now_s() - block_start;
        block_start = now_s();
        double eps = edges / (dt > 0 ? dt : window_s);
        double motor_rpm = (eps * 60.0) / pole_pairs;
        double rotor_rpm = motor_rpm / gear_ratio;

        printf("%.3f,%u,%.1f,%.0f,%.0f\n", now_s()-t0, edges, eps, motor_rpm, rotor_rpm);
        fflush(stdout);
    }

    FT_Close(ft);
    return 0;
}
EOF
```

# STEP F — Build a **Static** Binary (no runtime `.dylib`)

> This links against FTDI’s **static** library so your app runs anywhere without shipping extra files.

```bash
# (optional) Confirm the static library exists:
test -f release/build/libftd2xx.a || echo "Missing: release/build/libftd2xx.a"

# (optional) Check its architecture (arm64 preferred on Apple Silicon):
lipo -info release/build/libftd2xx.a

# Build:
clang -O2 -Wall rpm_reader.c -o rpm_reader_static \
  -Irelease \
  release/build/libftd2xx.a \
  -framework IOKit -framework CoreFoundation
```

**If the `.a` is x86\_64-only** and your Mac is Apple Silicon, use Rosetta to build & run:

```bash
arch -x86_64 clang -O2 -Wall rpm_reader.c -o rpm_reader_static_x86 \
  -Irelease \
  release/build/libftd2xx.a \
  -framework IOKit -framework CoreFoundation

arch -x86_64 ./rpm_reader_static_x86 --poles 14 --ratio 1.0
```

# STEP G — Run It

1. Plug **FT232H → Mac** (USB-C).
2. Power the ESC + motor (props removed).
3. Run:

```bash
cd ~/Desktop/FT232H_RPM
./rpm_reader_static --poles 14 --ratio 1.0 --index 0 --window 0.05
```

You’ll see CSV-style lines like:

```
# t_s, edges, edges_per_s, motor_rpm, rotor_rpm
0.050,120,2400.0,20571,20571
0.100,118,2360.0,20228,20228
```

**Parameters**

* `--poles` = total motor magnets (e.g., 14 ⇒ 7 pole-pairs)
* `--ratio` = motor\:rotor gear ratio (10.0 for 10:1)
* `--window` = sample window seconds (0.02–0.10 typical)
* `--index` = 0 unless you have multiple FTDI devices attached

**Log to CSV**

```bash
./rpm_reader_static --poles 14 --ratio 1.0 > rpm_log.csv
```

---

## Troubleshooting

* **Compiler can’t find headers**
  Ensure `release/ftd2xx.h` exists (we used `-Irelease`).

* **Missing `libftd2xx.a`**
  Confirm it’s at `release/build/libftd2xx.a`. If not present, re-download the macOS D2XX package. ([FTDI][3])

* **Architecture mismatch**
  If `lipo -info` shows only `x86_64` on an Apple-silicon Mac, use the Rosetta commands shown above or obtain an arm64 library.

* **Always zero edges**

  * Check wiring (AD0/D0 is bit 0 on FT232H).
  * Confirm **common ground** between ESC and FT232H.
  * Verify Castle AUX really is set to **RPM Out** and the motor is actually commutating.
  * Try a longer `--window 0.10` while testing.

* **Multiple FTDI devices**
  Try `--index 1` (etc.).

---

## Where to Buy (handy links)

* **Adafruit FT232H Breakout (USB-C)**: Adafruit store page. ([Adafruit][1])
* **Alternate FT232H listings** (retailers): examples on Amazon / Jameco / others. ([Amazon][5])
* **Castle Phoenix Edge Lite 50 product page** (reference/specs). ([Castle Homepage][2])
* **FTDI D2XX Drivers (macOS)** — official driver/SDK downloads. ([FTDI][3])

---

### Safety

Spin-testing can be dangerous. **Remove props**, clamp the motor/airframe, and keep clear while validating RPM.

---

We can extend this with a **“higher-rate” sampler** (synchronous bit-bang with buffered reads) and/or a small **I²C scan** utility next — both on the same FTDI D2XX stack.

[1]: https://www.adafruit.com/product/2264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 "Adafruit FT232H Breakout - General Purpose USB to GPIO ..."
[2]: https://www.castlecreations.com/en/phoenix-edge-lite-50-esc-010-0113-00?utm_source=chatgpt.com "PHOENIX EDGE LITE 50 AMP ESC, 8S / 34V WITH 5 ..."
[3]: https://ftdichip.com/drivers/d2xx-drivers/?utm_source=chatgpt.com "D2XX Drivers"
[4]: https://home.castlecreations.com/phoenix-edge-lite?utm_source=chatgpt.com "Phoenix Edge Lite — Castle Homepage"
[5]: https://www.amazon.com/Adafruit-Industries-FT232H-Breakout-General/dp/B09CJNVTS7?utm_source=chatgpt.com "Amazon.com: Adafruit Industries FT232H Breakout ..."

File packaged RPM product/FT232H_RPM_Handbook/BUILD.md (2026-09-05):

# Build & Run (macOS)

> Requires Apple Command Line Tools (`clang`) and the FTDI D2XX SDK files bundled in `vendor/ftdi/`.

## Static build (preferred — no runtime dylib)

```bash
cd "$(dirname "$0")/.."
clang -O2 -Wall src/rpm_reader.c -o rpm_reader_static   -Ivendor/ftdi   vendor/ftdi/libftd2xx.a   -framework IOKit -framework CoreFoundation
```

Run:

```bash
./rpm_reader_static --poles 14 --ratio 1.0 --index 0 --window 0.05
```

Log to CSV while keeping live output:

```bash
./rpm_reader_static --poles 8 --ratio 8.0 --index 0 --window 0.05 | tee rpm_log.csv
```

## Optional: Build device enumerator

```bash
clang -O2 -Wall src/list_ftdi.c -o list_ftdi   -Ivendor/ftdi vendor/ftdi/libftd2xx.a   -framework IOKit -framework CoreFoundation

./list_ftdi
```

## Notes

- `--poles` = total motor magnets (e.g., 8 or 14). Pole-pairs = poles/2.
- `--ratio` = motor:rotor gear ratio (e.g., 8.0 for 8:1).
- `--index` selects which FT232H to open (0, 1, ...).
- Increase `--window` (e.g., `0.10`) if CPU gets busy.

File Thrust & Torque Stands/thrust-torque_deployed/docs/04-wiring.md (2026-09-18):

# 04 - Wiring

> **Read this first if your board says VIN / VIO / GND / SCK / DAT / RATE.**
> That is the **Adafruit HX711 24-bit ADC (product 5974)**, and it is wired differently from
> the generic green module this document originally assumed. Jump to
> [Board A](#board-a---adafruit-hx711-24-bit-adc-product-5974). The single most important
> difference: **VIO is an output. Do not connect it to anything.**

There are two families of HX711 breakout in circulation and they do not share a pinout or a
pin-naming convention. Work out which one you have before you strip a single wire.

| If the silkscreen says... | You have | Wires to Arduino |
|---|---|---|
| VIN, VIO, GND, SCK, DAT, RATE - and RATE is a **slide switch** | **Board A**, Adafruit 5974 | 4 |
| VCC, VDD, DAT, CLK, GND - and a **YLW** pad near the terminals | **Board B**, SparkFun SEN-13879 | 5 (VCC and VDD both fed) |
| VCC, GND, DT, SCK - small green PCB, no VDD | **Board B**, generic green module | 4 |

The chip inside is the same in all three. The sketch does not care which you use. Only the
wiring differs.

Diagrams: `wiring-adafruit-hx711.svg` (Board A) and `wiring-generic-hx711.svg` (Board B).
Print the one that matches your board and keep it at the bench.

---

## Load cell to HX711

This part is the same on every board.

| Cell wire | HX711 pad | Function |
|---|---|---|
| Red | E+ | Bridge excitation, positive |
| Black | E- | Bridge excitation, negative |
| Green | A+ | Signal, positive |
| White | A- | Signal, negative |
| Shield / bare | **YLW** pad if present, otherwise GND | Ground at the HX711 end **only** |

Use **channel A**. The Adafruit board breaks out a second channel as B+ and B-; leave it
empty. Channel B has a fixed gain of 32 against channel A's 128, so a cell on B reads at a
quarter of the resolution. The sketch reads A only.

Colour convention is near-universal but not guaranteed. If your cell's datasheet disagrees,
follow the datasheet. Some cells substitute blue for green, or yellow for black.

If your cell has five wires, the fifth is the shield and is not part of the bridge. If it has
four, there is no shield, and you should consider running the cable inside a grounded braid,
because you are working next to motor phase leads carrying tens of amps of switched PWM.

**If the reading comes out negative when you expected positive, do not remount anything.**
Send `f` to the sketch to flip the sign in software. Do **not** swap green and white on
this rig: `f` is already load-bearing in the calibration procedure (see doc 05), and using
both fixes cancels them out. A reversed
reading means nothing except reversed wiring.

> Because this stand passes through **zero net load** partway up the thrust sweep, with the
> nacelle dead weight in compression below and thrust in tension above, sign handling is not
> cosmetic here. See doc 05 for the bidirectional calibration and the through-zero continuity
> check.

---

## Board A - Adafruit HX711 24-bit ADC (product 5974)

**Four wires. Not five.**

| Adafruit pin | Arduino pin | Wire |
|---|---|---|
| VIN | 5V | red |
| GND | GND | black |
| DAT | D2 | green |
| SCK | D3 | violet |
| **VIO** | **- nothing -** | leave unconnected |
| **RATE** | **- nothing -** | it is a switch, see below |

### VIO is an output, not an input

This is the one that bites, because the name looks like a supply input and on a different
board it would be.

On the Adafruit board, **VIO is the on-chip regulator's digital-supply output**, brought to a
pad so you can measure it or borrow it for something else. It is not asking to be fed.
Jumpering it to VIN ties the regulator's output to your 5 V rail and puts them in opposition.

The confusion is understandable: SparkFun's board has a **VDD** pin that genuinely is a logic
level input you must feed, and plenty of hookup guides say "short VCC and VDD together."
That advice is correct for that board and wrong for this one.

**Leave VIO unconnected and the board just works.**

### VIN sets the logic level

Feed VIN the same voltage as your microcontroller's logic. The Nano is a 5 V part, so VIN
goes to the Nano's 5V pin. On a 3.3 V board you would give VIN 3.3 V instead. There is no
separate level pin to worry about, which is precisely why VIO is not one.

### RATE is a slide switch

There is no RATE wire to run. On the right-hand edge of the board is a slide switch marked
Rate, with positions L and H.

- **L gives 10 samples per second.** This is what the supplied sketch expects. **Set it to L.**
- H gives 80 SPS.

If you later want 80 SPS for more averaging, that is a reasonable change, but move the switch
and adjust the sketch's timing together, not one without the other.

### Terminal blocks

The Adafruit board ships with the screw terminals pre-soldered, which is genuinely convenient
for a stand that will be assembled and disassembled repeatedly as post sections change. Six
positions: E+, E-, A+, A-, B+, B-. Strip about 6 mm, insert, tighten, and **tug each wire**.
A screw terminal that looks seated and is not is a fault that appears only under vibration,
which is to say only when the rotor is turning.

---

## Board B - SparkFun SEN-13879 and generic green modules

| HX711 pin | Arduino pin |
|---|---|
| VCC | 5V |
| **VDD** | **5V** (SparkFun only - jumper to VCC) |
| GND | GND |
| DAT / DT / DOUT | D2 |
| CLK / SCK | D3 |

**DAT, DT and DOUT are three silkscreen names for one pin.** SparkFun prints DAT, generic
green boards print DT or DOUT, and the sketch calls it `PIN_DOUT`. All the same signal.

**VCC versus VDD on the SparkFun board.** VCC is the analogue supply that excites the cell;
VDD sets the digital logic level. For a 5 V Nano, jumper them together and feed both from 5V.
They are separate only so a 3.3 V microcontroller can run VCC at 5 V for bridge headroom
while keeping VDD at 3.3 V for safe logic. Not your case.

Generic green modules have a single VCC and no VDD pad at all. Nothing to jumper.

**RATE on Board B** is pin 15 of the bare chip. Green modules usually tie it low at 10 SPS
from the factory, which is what you want. Changing it means lifting a pin, and it is not
worth the surgery.

---

## Pin assignment conflict - read before you follow any other guide

SparkFun's hookup guide and their example sketches use `DAT = 3, CLK = 2`.
**This package uses `DAT = D2, SCK = D3`.** They are transposed.

Neither is more correct; the HX711 works on any two GPIO pins. But if you wire to one
convention and run the other's software, **you get nothing and no error message.** It looks
exactly like a dead board, and people replace perfectly good hardware over it.

Pick one and stay with it. To follow SparkFun's convention instead, swap two lines at the top
of `thrust_stand.ino`:

```cpp
const uint8_t PIN_DOUT = 3;   // was 2
const uint8_t PIN_SCK  = 2;   // was 3
```

Nothing else in the sketch is affected.

**Do not use D0 or D1** on any board. Those are the hardware serial pins the USB connection
uses, and anything on them fights the serial link.

---

## Elegoo Nano V3.0 specifics

The headers ship loose, so you can solder only the four pads this project needs. They are
placed conveniently:

```
   ANALOG SIDE                        DIGITAL SIDE
   ...                                ...
   A6                                 D4
   A7                                 D3   <-- SCK
 > 5V   <-- HX711 VIN (or VCC)        D2   <-- DAT
   RST                                GND  <-- HX711 GND
   GND                                RST
   VIN                                RX0   (do not use)
                                      TX1   (do not use)
```

**D3, D2 and GND are three consecutive pads** on the digital side. Only 5V is on the opposite
edge. Four solder joints total.

Note the collision of names: the **Nano** also has a pin called VIN, and it is the raw
unregulated input, typically 7 to 12 V. **Never connect the HX711's VIN to the Nano's VIN.**
HX711 VIN goes to the Nano's **5V** pad. On a stand sitting next to a 6S pack this is not a
theoretical hazard.

---

## Supply quality

The HX711 is a **ratiometric** converter. It excites the bridge from the same rail it uses as
the ADC reference, so a rail sitting at 4.7 V instead of 5.0 V does not shift your reading.
The two effects cancel.

What it will not tolerate is a rail sagging far enough that the internal analogue regulator
runs out of headroom. Practically: plug into a real USB port on the laptop, not an unpowered
hub, and use a short thick cable. A thin two-metre USB cable is a common and very annoying
cause of slow unexplained drift.

---

## Power and grounding, and this matters

**Power the Arduino from the laptop USB. Do not power it from the flight pack.**

You are reading a millivolt-level bridge inches from motor phase wires carrying tens of amps
of switched PWM. Every rule below exists to keep that noise out.

- Ground the cell's shield at the **HX711 end only.** Grounding both ends makes a loop antenna.
- Run the cell cable down the **opposite side of the post** from the motor phase leads.
- If they must cross, cross at 90 degrees.
- Keep the HX711 close to the cell and put the long run on the **digital** side. Signal from
  the cell is millivolts; signal from the HX711 is logic level and far more robust.
- Leave a **service loop** in the cell cable, taped to the post, so cable tension never enters
  the load path. A taut cable is a spring in parallel with your load cell.

**Diagnostic:** if readings are clean with the motor off and turn to hash under power, it is
one of the above. Almost always the shield or the cable routing.

---

## Troubleshooting

| Symptom | Likely cause |
|---|---|
| `HX711 ready: no` | DAT and SCK swapped, or on the wrong pins for the sketch. Check the transposition warning above. |
| Board warm, no data | VIO jumpered to VIN on an Adafruit board. Remove that wire. |
| Reads but sign inverted | Expected after calibrating. Send `f`. Do not swap the wires. |
| Readings drift slowly, no load | Thin or long USB cable; unpowered hub; or cable tension in the load path. |
| Clean cold, hash under power | Shield grounded at both ends, or cell cable routed alongside phase leads. |
| Value frozen, never changes | SCK stuck high - HX711 enters power-down after 60 µs of SCK high. Check the D3 joint. |
| Steps or jumps mid-sweep | Not electrical. Threaded-joint clearance at the load reversal. See doc 03 preload and doc 05. |

---

## Sample rate

10 SPS suits this test: plateaus are five seconds long, so you get roughly fifty samples per
point. 80 SPS gives the software more to average vibration out of, which is mildly preferable
on a thrust stand, but it is not worth changing the sketch timing for. On Board A it is one
switch; on Board B it is surgery. Either works.

---

## Diagram files

- `wiring-adafruit-hx711.svg` - Board A, Adafruit 5974
- `wiring-generic-hx711.svg` - Board B, SparkFun and generic green

Both show the full chain: load cell, HX711, Arduino, and the shield path. Print the one that
matches your board.

---

## Optional additions

- **SD card module** for standalone logging without a laptop. SPI, pins 10 to 13 on an Uno.
- **OLED display** if you want a number at the bench. I2C, A4 and A5 on an Uno.

Neither is in the supplied sketch. Serial to a laptop is simpler and gives you the log file
you actually need.

---

## The power side

Thrust and electrical power are measured by **separate instruments** and that is fine.

Put an inline watt meter or a shunt between the pack and the ESC. Do not use ESC-reported
current for the deliverable; it is commonly 5 to 10 percent off.

Size the meter for **50 A per nacelle**, not for the hover figure. Hover is **21 A at 21 V**
(446 W per nacelle from flight test; the 12 to 13 A in earlier versions of this document was
a model figure and was wrong), and peak thrust draw is roughly double that. A meter clipping
at peak loses you exactly the data point that matters for control authority.

The same 21 A applies to everything else in the power path. Pack leads, the loom to the
nacelle, and every connector it passes through must be rated for it with margin. In
particular, if you are running pack or phase current through a Micro-Fit 3.0, one circuit is
good for about 8.5 A with 18 AWG and derates further with all fourteen energised; that
connector is fine for signals and wrong for power unless several circuits are paralleled per
the derating chart.

You do **not** need synchronised instruments. Because the test is a staircase with five second
plateaus, you read the settled value off each device independently and write the row. The
plateau does the synchronising for you. This saves an enormous amount of grief and costs
nothing in data quality.

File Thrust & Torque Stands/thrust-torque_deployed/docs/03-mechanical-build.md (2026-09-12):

# 03 - Mechanical Build

The load path, top to bottom:

```
        prop (914 mm disc, R = 457)
             |
        nacelle
             |
        trunnion axis  <-- clamped by yoke
             |
        yoke
             |
        upper adapter plate
             |
        stud + jam nut
             |
   ==== S-BEAM LOAD CELL ====   <-- everything above this is measured
             |
        stud + jam nut
             |
        lower adapter plate
             |
        post  (sets height z)    <-- everything below this is NOT measured
             |
        three splayed legs
             |
        floor
```

The line through the cell is the whole design. Anything above it appears in the reading.
Anything below it does not. That is why the cell goes **directly under the nacelle** and
not partway down the post.

---

## Blade and hub interface - locked, do not redesign

The rotor is Austin's **SOLID CORE V49** blade pair. The blade-to-grip interface is fixed
and is not something this stand gets to have an opinion about. It is recorded here because
it is easy to measure the wrong thing.

**The supplied STL files are printed CORES, not finished blades.** The carbon layup adds
**1.0 mm per side**. Every dimension below is core-versus-finished, and confusing the two
will make a correctly-designed joint look like an interference.

| | Width | Thickness |
|---|---|---|
| Core tang, measured off the STL | 14.25 mm | 7.00 mm |
| Plus 1.0 mm carbon per side | +2.0 | +2.0 |
| **Finished blade root** | **16.25 mm** | **9.00 mm** |

Against the grip:

| Feature | Value | Source |
|---|---|---|
| Grip outside diameter | 16.0 mm | drawing |
| Flats, across | 9.0 mm | drawing |
| Resulting flat face width | 13.2 mm | drawing, and 2*sqrt(8^2 - 4.5^2) = 13.23 confirms it |
| Grip length | 49 mm, r = 31 to 80 | drawing, and the STL tang measures exactly 49 mm |
| Bolt holes | 5.0 mm, at r = 40 and r = 65 | drawing, matching `CENTER_HUB_to_DIVOT1/2` |
| Bolt spacing | 25 mm | 65 - 40 |
| Outboard bolt to grip end | 15 mm | 80 - 65 |
| Bearings | 8 mm OD on 5 mm bolts | Austin's source |

Finished thickness of 9.00 mm sits **exactly** on the 9.0 mm flats. Finished width of
16.25 mm is 0.25 mm over the 16.0 mm diameter, which is precisely why Austin's source reads
`gripper_hgt = 9.0 - 0.25` with a note that he built it to 9 mm and sanded to fit.

**Do not scale anything off the STL root as though it were the finished part.** It is 2 mm
undersize in both directions by design.

### The one measurement that matters to this rig

The whole test matrix, the z/R ladder and every power figure in doc 01 are anchored to
**R = 457 mm, hub centreline to blade tip**.

The blade root face sits at r = 31 mm and the blade is 426 mm long, which is what produces
457. If your assembled hub puts the root face anywhere other than 31 mm from the rotor
centreline, **R is not 457 and the labels on your data are wrong.**

Measure it once, with calipers, on the assembled head. Write the number in the run log. If
it comes out other than 457, pass it to `reduce.py` with `--radius` and recompute the height
ladder as z/R times the measured value. Do not just carry on with the printed table.

## Step 1 - Build the yoke

Your nacelle already has a trunnion where the wing carries it. Build a U-shaped yoke that
captures that tube, with pinch bolts closing the open end.

You are not inventing a mount. You are copying the one the aircraft already uses, which is
the answer to the stability question: the trunnion is strong enough and stiff enough to
carry this nacelle in flight, so it is strong enough here.

Index the yoke so the **rotor axis is vertical** when the trunnion is clamped. Mark that
index position so you can return to it exactly after any disassembly.

Bonus: if you make the yoke indexable at intermediate tilt angles, the same fixture
characterises thrust and watts through the transition, not just at hover. That may be worth
more to Vermont than the hover number alone.

## Step 2 - Upper adapter plate

The yoke bolts to a flat plate, minimum three bolts. One bolt will wobble and rotate; three
on a plate is a stand. The underside of this plate is the mating face for the load cell, so
it must be flat and clean. You need friction across that joint.

Drill the centre for the stud, and if you are fitting an anti-rotation dowel, drill for it
now, offset from centre.

## Step 3 - Fit the load cell

Thread a stud into the cell's upper hole. The ATO 20 kg cell is **M8 x 1.25**, standard
coarse pitch, so studs and jam nuts are off-the-shelf. Get about **1.5 diameters of
engagement**, so roughly 12 mm.

Cell envelope for your CAD: 60 mm wide, 58 mm tall, 12 mm thick, threaded holes on the
vertical centreline. Full table in `docs/11-load-cell-datasheet.md`.

**Do not let the stud bottom out in the hole.** If it bottoms and you keep turning, you jack
the cell body apart from the inside and permanently shift its zero. Run it until snug on the
plate face, then lock with the jam nut.

Repeat at the bottom into the lower adapter plate.

Rules that are not optional:

- **Nothing clamps the middle of the cell.** That is where the strain gauges live. It has to
  stay free to flex.
- **No compliance in the joints.** No rod ends, no rubber, no crush washers. Compliance
  shows up as lag and hysteresis in your data.
- **No brace bridges the cell.** If you brace the post, the brace attaches below the cell.
  A brace across the cell shunts load around it and you measure a fraction of the truth
  without knowing it.

## Step 4 - Anti-rotation

Motor torque at hover is about 1 N-m, under a foot-pound, trying to unscrew the stack.
Friction from a properly preloaded M8 on a flat plate face handles it easily.

Check your prop rotation direction against the thread hand. If reaction torque wants to
unscrew the joint, fit the dowel pin through both plates offset from centre and stop
worrying about it. Thread locker on both studs regardless.

**Both studs must be properly made up and tight.** They are not just holding the stack
together; they are the tension path. Nacelle dead weight presses down on the cell, rotor
thrust pulls up on it, and the cell reads straight through zero between the two. If a stud
is loose, or if anything in the stack merely rests rather than bolts, you lose every reading
above dead weight, which is most of the range you came here to measure. Doc 05 explains the
sign handling that follows from this.

## Step 5 - Alignment

This is the one thing that can silently corrupt the reading.

The cell's measuring axis must be **vertical and coincident with the rotor axis**. Thrust
then arrives as pure axial load, which is what an S-beam measures well. Check with a level
on the plate faces and a plumb line from the hub.

**Get the CG on the post centreline.** Balance the assembly on the post with the motor off
and shim until it sits without wanting to fall one way. If you cannot get it close, add a
counterweight to the fixture.

This matters for two separate reasons and they are worth separating:

- **Measurement:** a constant bending moment from an offset CG is absorbed by the tare, so
  it does not corrupt the reading. This part is genuinely forgiving.
- **Survival:** ATO's own guidance for this cell is explicit that it must be installed
  without transverse load, and that load applied offset from the centre axis damages the
  sensor. Their transverse load limit is 100% F.S. An S-beam is built to be loaded along
  its axis and is comparatively weak in bending.

So do not skip alignment on the grounds that the tare handles it. The tare protects your
data, not your cell. Never lever the nacelle into position with the cell in the stack, and
never let the fixture apply a side load or a twist.

Beyond that, the geometry only needs to hold still between tare and run. No slop, nothing
shifting, and re-tare after anything is bumped.

## Step 6 - Post and height sections

Round steel tube, 25-38 mm OD. Round because it is stiff in torsion and has no preferred
bending plane.

Cut discrete sections for each height in the ladder rather than using a pinned telescope.
A pinned telescope has a few thou of slop, and slop between tare and run is exactly the
error mode you are trying to avoid. If you must telescope, use a clamping collar, not a pin.

Post length is measured so that the **rotor plane** lands at the target height, not the top
of the post. Account for the stack height of plates, cell and nacelle. Measure the actual
assembled rotor height with a tape at every ladder step and record it. Do not trust the cut
length.

## Step 7 - Legs

Three legs, splayed, feet landing **outside 700 mm radius** from the axis so nothing solid
sits under the rotor.

Anchor to concrete, or ballast each foot with 25 lb. The rig must not walk, rock or ring.

Again: no solid base plate under the disc. It would act as a false ground plane and corrupt
the exact measurement you are making.

## Step 8 - Pre-flight mechanical check

Before power, with the prop fitted:

- [ ] Rotor axis vertical, plumbed from hub
- [ ] All plate bolts to torque
- [ ] Jam nuts locked, thread locker cured
- [ ] Nothing bridging the cell
- [ ] Cell cable strain-relieved with a service loop, not tight
- [ ] Legs anchored or ballasted, no rock
- [ ] Prop bolts to torque, prop balanced
- [ ] Rotor height measured and written down
- [ ] Floor clear for three rotor diameters, roughly 1.8 m each way

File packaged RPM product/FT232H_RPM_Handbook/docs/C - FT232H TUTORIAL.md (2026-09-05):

# FT232H → macOS: Real-Time RPM from Castle ESC (No Python)

> Outcome: a self-contained binary (`rpm_reader_static`) that reads the Castle **AUX (white) RPM OUT** via **FT232H** and prints RPM in real time.

---

## What You’ll Need

* **FT232H breakout (USB-C, STEMMA QT)** — e.g., Adafruit Product 2264. ([Adafruit][1])
* **Your Castle Phoenix Edge Lite 50 ESC** (any Edge/Edge Lite with AUX works). ([Castle Homepage][2])
* **1 kΩ resistor** (series protection on the AUX signal).
* **Jumper wires**.
* **Mac with Apple Command Line Tools** (`clang`). Check with:

  ```bash
  clang --version
  ```
* **FTDI D2XX (macOS) SDK/driver** (we’ll use its headers + static library). ([FTDI][3])

---

# STEP A — Wire It (2 connections)

**Do not** power FT232H from the ESC — it’s USB-powered from your Mac.

```
[ESC] AUX (white) ──[ 1 kΩ ]──► AD0 / D0  (FT232H)
[ESC] GND (black)  ───────────► GND       (FT232H)
```

**Notes**

* Shared ground is essential.
* The AUX (white) must be configured to **RPM Out** in Castle Link (one-time config, see Step 6).

# STEP B - Configure Castle ESC AUX = RPM OUT (Castle Link Classic)

> Props off. Bench test only.

## 1) Hardware hookup (in the right order)

1. **Unplug** the ESC **AUX/white** lead from any receiver/device. Castle specifically warns to disconnect AUX before linking. ([Castle Homepage][1])
2. Plug the ESC’s **3-wire throttle lead** into the **Castle Link USB** adapter. ([Castle Homepage][1])
3. Connect the Castle Link USB adapter to your **Windows PC** (Castle Link runs on Windows).
4. **Then** power the ESC from its main battery. (Castle notes applying main power after you’ve connected the USB link.) ([Castle Homepage][1])

> If Castle Link can’t “see” the ESC, recheck this order and that AUX is unplugged.

## 2) Open Castle Link (Classic)

* Launch **Castle Link Classic** (the “legacy” UI—distinct from Castle Link 2). Castle’s own article shows both Classic and the newer “Castle Link 2,” and confirms Classic is still used with the V3 USB kit. ([Castle Homepage][2])

> If you only have Castle Link 2 installed, no problem—the setting name is the same. The path may look a bit different visually.

## 3) Read the ESC & (optional) update firmware

* Wait for the software status bar to show your ESC is connected; use **Update/Read** to pull settings.
* If a firmware update prompt appears, you can accept it now for best compatibility. (Castle Link article covers firmware updating with Classic.) ([Castle Homepage][2])

## 4) Find the AUX Wire setting

* In **Castle Link Classic**, go to the menu/tab where **AUX / Auxiliary Wire Mode** is listed (on Edge/Edge Lite, AUX modes are selectable only via Castle Link). The Edge user guide states the **AUX line is disabled until a mode is selected** with Castle Link. ([Minicars][3])

> Depending on version, you’ll see AUX items among the advanced/other menus. Castle’s docs and product pages describe the AUX as the **“user-programmable white wire.”** ([Castle Homepage][4])

## 5) Select **RPM OUT**

* Choose **RPM OUT** for **AUX Wire Mode**.
* Castle’s Edge manuals and tech tip define RPM OUT as:
  **“The ESC toggles the AUX line at every electrical commutation. Divide by magnetic pole-pairs to get mechanical RPM.”** ([LeoMotion Download][5])

*(Optional)* Leave “Idle Datalog Erase” **off** unless you want AUX toggling at idle to clear logs. (Castle calls this out as an add-on behavior in Castle Link.) ([Castle Homepage][6])

## 6) Write settings & power-cycle

* Click **Update/Write** (or **Send Settings to Controller**) to save.
* **Disconnect** main power, then remove the USB link.
* Your **white wire now outputs a TTL pulse train** proportional to commutation. (You’ll use that for your FT232H reader, flight controller capture, or an I²C tach bridge.)

## 7) Verify the output (quick sanity)

* Re-power the ESC (still no prop), run the motor slowly, and probe the white wire vs GND with a scope or your working FT232H reader. You should see pulses that increase with throttle.
* Mechanical RPM ≈ *(edges/sec × 60) / pole-pairs*. (Pole-pairs = total magnets ÷ 2.) ([LeoMotion Download][5])

---

## Notes & references

* **AUX modes & RPM OUT definition (Edge manuals & tech tip)**: AUX is user-selectable; **RPM OUT toggles every electrical commutation**. ([LeoMotion Download][5])
* **Castle Link connection order & AUX disconnect warning** (downloads page): unplug AUX → connect Castle Link → then apply main power. ([Castle Homepage][1])
* **Classic vs Castle Link 2** (what you’re looking at): Castle’s “Castle Link Explained” article shows both UIs and when each is used. ([Castle Homepage][2])
* **Product pages reaffirm AUX = programmable white wire** on Edge series. ([Castle Homepage][7])

# STEP C — Get the FTDI D2XX SDK (macOS)

Download FTDI’s **D2XX** package for macOS. It contains:

* `ftd2xx.h` and `WinTypes.h` (headers)
* `build/libftd2xx.a` (static library) — we’ll link this to avoid any runtime `.dylib`
* Samples & notes

> FTDI D2XX driver page: **D2XX Drivers** → **Mac OS X** download. ([FTDI][3])

Assume you place/extract it at:

```
~/Desktop/FT232H_RPM/release/
  ftd2xx.h
  WinTypes.h
  build/
    libftd2xx.a
    libftd2xx.1.4.30.dylib  (not needed for static build)
```

---

# STEPH D — Create a Clean Project Folder

```bash
mkdir -p ~/Desktop/FT232H_RPM
cd ~/Desktop/FT232H_RPM
```

Confirm you have the SDK files there (either keep them in `release/` or copy them in). We’ll reference them **in place**:

```
~/Desktop/FT232H_RPM/
  release/ftd2xx.h
  release/WinTypes.h
  release/build/libftd2xx.a
```

---

# STEP E — Add the RPM Reader Source

Create `rpm_reader.c`:

```bash
cat > rpm_reader.c <<'EOF'
// rpm_reader.c — FT232H + D2XX RPM reader (static link)
// Wiring: ESC white AUX -> 1k -> FT232H AD0 (D0); ESC GND -> FT232H GND
// Usage:  ./rpm_reader_static --poles 14 --ratio 1.0 --index 0 --window 0.05

#include <stdio.h>
#include <stdlib.h>
#include <stdint.h>
#include <string.h>
#include <time.h>
#ifdef __APPLE__
#include <mach/mach_time.h>
#endif

#include "ftd2xx.h"

static int    motor_poles = 14;     // total magnets, 14 => 7 pole-pairs
static double gear_ratio  = 1.0;    // motor:rotor (10.0 for 10:1)
static int    dev_index   = 0;      // FTDI device index to open
static double window_s    = 0.05;   // seconds per RPM sample

static double now_s(void) {
#ifdef __APPLE__
    static mach_timebase_info_data_t tb;
    static uint64_t start = 0;
    if (!tb.denom) mach_timebase_info(&tb);
    if (!start) start = mach_absolute_time();
    uint64_t t = mach_absolute_time() - start;
    double ns = (double)t * (double)tb.numer / (double)tb.denom;
    return ns * 1e-9;
#else
    struct timespec ts; clock_gettime(CLOCK_MONOTONIC, &ts);
    return (double)ts.tv_sec + (double)ts.tv_nsec * 1e-9;
#endif
}

static void usage(const char *p) {
    fprintf(stderr,
      "Usage: %s [--poles N] [--ratio R] [--index I] [--window S]\n"
      "  --poles   Total motor poles (default 14)\n"
      "  --ratio   Gear ratio motor:rotor (default 1.0)\n"
      "  --index   FTDI device index to open (default 0)\n"
      "  --window  Seconds per RPM sample (default 0.05)\n", p);
}

static void die(const char *msg, FT_STATUS st) {
    fprintf(stderr, "%s (FT_STATUS=%ld)\n", msg, (long)st);
    exit(1);
}

int main(int argc, char **argv) {
    for (int i=1; i<argc; ++i) {
        if (!strcmp(argv[i], "--poles") && i+1<argc)      motor_poles = atoi(argv[++i]);
        else if (!strcmp(argv[i], "--ratio") && i+1<argc) gear_ratio  = atof(argv[++i]);
        else if (!strcmp(argv[i], "--index") && i+1<argc) dev_index   = atoi(argv[++i]);
        else if (!strcmp(argv[i], "--window") && i+1<argc)window_s    = atof(argv[++i]);
        else { usage(argv[0]); return 1; }
    }
    if (motor_poles < 2) motor_poles = 2;
    int pole_pairs = motor_poles / 2; if (pole_pairs < 1) pole_pairs = 1;
    if (gear_ratio <= 0.0) gear_ratio = 1.0;
    if (window_s < 0.01) window_s = 0.01;

    FT_STATUS st;
    FT_HANDLE ft;

    st = FT_Open(dev_index, &ft);
    if (st != FT_OK) die("FT_Open failed", st);

    FT_SetLatencyTimer(ft, 2); // ms

    UCHAR mask = 0x00; // all inputs
    UCHAR mode = 0x01; // async bit-bang
    st = FT_SetBitMode(ft, mask, mode);
    if (st != FT_OK) die("FT_SetBitMode failed", st);

    printf("# t_s, edges, edges_per_s, motor_rpm, rotor_rpm\n");
    double t0 = now_s();
    double block_start = t0;

    UCHAR prev=0, cur=0;
    st = FT_GetBitMode(ft, &prev);
    if (st != FT_OK) die("FT_GetBitMode (init) failed", st);
    prev &= 0x01; // AD0

    for (;;) {
        unsigned edges = 0;
        double deadline = block_start + window_s;

        while (now_s() < deadline) {
            st = FT_GetBitMode(ft, &cur);
            if (st != FT_OK) die("FT_GetBitMode failed", st);
            UCHAR bit = cur & 0x01; // AD0 (LSB)
            if (!prev && bit) edges++;
            prev = bit;
        }

        double dt = now_s() - block_start;
        block_start = now_s();
        double eps = edges / (dt > 0 ? dt : window_s);
        double motor_rpm = (eps * 60.0) / pole_pairs;
        double rotor_rpm = motor_rpm / gear_ratio;

        printf("%.3f,%u,%.1f,%.0f,%.0f\n", now_s()-t0, edges, eps, motor_rpm, rotor_rpm);
        fflush(stdout);
    }

    FT_Close(ft);
    return 0;
}
EOF
```

---

# STEP F — Build a **Static** Binary (no runtime `.dylib`)

> This links against FTDI’s **static** library so your app runs anywhere without shipping extra files.

```bash
# (optional) Confirm the static library exists:
test -f release/build/libftd2xx.a || echo "Missing: release/build/libftd2xx.a"

# (optional) Check its architecture (arm64 preferred on Apple Silicon):
lipo -info release/build/libftd2xx.a

# Build:
clang -O2 -Wall rpm_reader.c -o rpm_reader_static \
  -Irelease \
  release/build/libftd2xx.a \
  -framework IOKit -framework CoreFoundation
```

**If the `.a` is x86\_64-only** and your Mac is Apple Silicon, use Rosetta to build & run:

```bash
arch -x86_64 clang -O2 -Wall rpm_reader.c -o rpm_reader_static_x86 \
  -Irelease \
  release/build/libftd2xx.a \
  -framework IOKit -framework CoreFoundation

arch -x86_64 ./rpm_reader_static_x86 --poles 14 --ratio 1.0
```

---

# STEP G — Configure the ESC AUX to **RPM Out** (one time)

Open **Castle Link** on Windows (using the Castle Link USB adapter), connect the ESC, and set the **AUX/White Wire** function to **RPM Out** (naming can vary slightly by firmware UI, but look for AUX/Auxiliary Wire Mode). On Edge/Edge Lite, AUX supports RPM and telemetry modes. ([Castle Homepage][4])

> Tip: After you save/apply settings, power-cycle the ESC.

---

# STEP H — Run It

1. Plug **FT232H → Mac** (USB-C).
2. Power the ESC + motor (props removed).
3. Run:

```bash
cd ~/Desktop/FT232H_RPM
./rpm_reader_static --poles 14 --ratio 1.0 --index 0 --window 0.05
```

You’ll see CSV-style lines like:

```
# t_s, edges, edges_per_s, motor_rpm, rotor_rpm
0.050,120,2400.0,20571,20571
0.100,118,2360.0,20228,20228
```

**Parameters**

* `--poles` = total motor magnets (e.g., 14 ⇒ 7 pole-pairs)
* `--ratio` = motor\:rotor gear ratio (10.0 for 10:1)
* `--window` = sample window seconds (0.02–0.10 typical)
* `--index` = 0 unless you have multiple FTDI devices attached

**Log to CSV**

```bash
./rpm_reader_static --poles 14 --ratio 1.0 > rpm_log.csv
```

---

## Troubleshooting

* **Compiler can’t find headers**
  Ensure `release/ftd2xx.h` exists (we used `-Irelease`).

* **Missing `libftd2xx.a`**
  Confirm it’s at `release/build/libftd2xx.a`. If not present, re-download the macOS D2XX package. ([FTDI][3])

* **Architecture mismatch**
  If `lipo -info` shows only `x86_64` on an Apple-silicon Mac, use the Rosetta commands shown above or obtain an arm64 library.

* **Always zero edges**

  * Check wiring (AD0/D0 is bit 0 on FT232H).
  * Confirm **common ground** between ESC and FT232H.
  * Verify Castle AUX really is set to **RPM Out** and the motor is actually commutating.
  * Try a longer `--window 0.10` while testing.

* **Multiple FTDI devices**
  Try `--index 1` (etc.).

---

## Where to Buy (handy links)

* **Adafruit FT232H Breakout (USB-C)**: Adafruit store page. ([Adafruit][1])
* **Alternate FT232H listings** (retailers): examples on Amazon / Jameco / others. ([Amazon][5])
* **Castle Phoenix Edge Lite 50 product page** (reference/specs). ([Castle Homepage][2])
* **FTDI D2XX Drivers (macOS)** — official driver/SDK downloads. ([FTDI][3])

---

### Safety

Spin-testing can be dangerous. **Remove props**, clamp the motor/airframe, and keep clear while validating RPM.

---

We can extend this with a **“higher-rate” sampler** (synchronous bit-bang with buffered reads) and/or a small **I²C scan** utility next — both on the same FTDI D2XX stack.

[1]: https://www.adafruit.com/product/2264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 "Adafruit FT232H Breakout - General Purpose USB to GPIO ..."
[2]: https://www.castlecreations.com/en/phoenix-edge-lite-50-esc-010-0113-00?utm_source=chatgpt.com "PHOENIX EDGE LITE 50 AMP ESC, 8S / 34V WITH 5 ..."
[3]: https://ftdichip.com/drivers/d2xx-drivers/?utm_source=chatgpt.com "D2XX Drivers"
[4]: https://home.castlecreations.com/phoenix-edge-lite?utm_source=chatgpt.com "Phoenix Edge Lite — Castle Homepage"
[5]: https://www.amazon.com/Adafruit-Industries-FT232H-Breakout-General/dp/B09CJNVTS7?utm_source=chatgpt.com "Amazon.com: Adafruit Industries FT232H Breakout ..."

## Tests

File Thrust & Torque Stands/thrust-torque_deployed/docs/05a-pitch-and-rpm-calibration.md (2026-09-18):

# 05a - Pitch and RPM Calibration

Do this **before** the load cell work in doc 05 is put to use, and certainly before any run
in doc 06. It is bench work, no rotor spinning for part one.

Two calibrations:

1. Servo microseconds to **blade pitch at 0.75R**
2. Throttle command to **governed RPM**

Neither takes long. Skipping either means your inner test axis is servo counts, which are
meaningless to anyone reading the report and not comparable between builds.

---

## Part 1 - Servo microseconds to blade pitch

### Why 0.75R

Blade pitch varies continuously along the span; this blade has **33.3 degrees** of built-in
washout between r/R 0.22 and the tip. So "the pitch" is not a number unless you say where.
The rotor convention is the three-quarter radius station, and that is what the predictions in
doc 01 and doc 06 are quoted at.

At R = 457 mm, **0.75R is r = 343 mm from the hub centreline**. Mark it on the blade with a
fine pen before you start. On the supplied V49 blade the chord there is 33.8 mm, essentially
the widest part of the blade.

### What you need

- A pitch gauge that clamps on the blade. A digital-readout heli pitch gauge is ideal.
- A servo tester or your transmitter, able to command specific microsecond values.
- A way to hold the head still with the blades free to feather.

### Procedure

1. Support the nacelle so the head cannot rotate but the blades can pitch freely.
2. Level the reference. Most pitch gauges zero against the shaft or the head; follow the
   gauge's own convention and **write down which one you used.**
3. Clamp the gauge at the 0.75R mark on **blade A**.
4. Command a series of servo values across the working range and record pitch at each:

| Servo (us) | Pitch at 0.75R, blade A | Pitch at 0.75R, blade B | Difference |
|---|---|---|---|
| 1100 | | | |
| 1200 | | | |
| 1300 | | | |
| 1400 | | | |
| 1500 | | | |
| 1600 | | | |
| 1700 | | | |
| 1800 | | | |
| 1900 | | | |

5. Repeat every row on **blade B without moving anything else.**

### What good looks like

- **Linearity.** Pitch against microseconds should be close to a straight line over the
  working range. Some curvature at the extremes is normal; a kink in the middle is not, and
  usually means a linkage is binding or a ball link is at the end of its travel.
- **Tracking.** Blade A and blade B should agree within about **0.2 degrees** at every step.
  A constant offset means one pitch link needs adjusting. An offset that **grows** with
  collective means the two links are at different geometry, which is worse and needs fixing
  before you fly, never mind before you test.
- **Range.** You need to reach at least 18 degrees at 0.75R to find the thrust ceiling at
  1600 rpm. Confirm you have it before you build the test matrix. If you also want the
  torque stand to reach cruise torque (1.39 N·m at 1000 rpm) the head needs pitch well past
  22 degrees, in deep stall; note the mechanical limit while the gauge is on.

Fit a straight line to the blade-A column and keep the slope and intercept. That is your
conversion for the whole test campaign. Write it at the top of the run log.

> **The 45 degree pitch-link phase advance is a different thing.** The control system has a
> 45 degree advance to counter rotor lag. That is about *when* in the rotation a control
> input arrives, not *how much* pitch a servo command produces. It has no bearing on this
> calibration. Do not let the number 45 and the number 33.3 (the blade's built-in twist) get
> mixed together in your notes; they are unrelated quantities that happen to be similar in
> magnitude.

---

## Part 2 - Throttle command to governed RPM

This part does spin. Read doc 09 first, and do it at the **OGE height** with the rig fully
tied down.

### Procedure

1. Set collective to **minimum**. You want the governor working against as little load as
   possible so it can hold the setpoint cleanly.
2. Spool up gently to the lowest setpoint you intend to use.
3. Let it settle a full **ten seconds**. Governors take longer to settle than you expect.
4. Record commanded throttle and **measured** RPM, from an optical tach or telemetry.
5. Step through the ladder:

| Throttle cmd | Target RPM | Measured RPM (flat pitch) | Delta |
|---|---|---|---|
| | 1600 | | |
| | 1700 | | |
| | 1800 | | |
| | 1900 | | |
| | 2000 | | |

6. Spool down.

### What good looks like

- Measured RPM within about **2 percent** of target at flat pitch. If it cannot hold the
  setpoint with no aerodynamic load on it, it certainly will not hold it at 15 degrees of
  collective.
- **Stable.** Watch for hunting: a slow periodic surge in RPM and current. On a rigid stand
  there is no airframe mass to damp the loop, so a governor that is perfectly well behaved in
  flight can oscillate here. If it hunts, reduce the governor gain and note the value you
  used, because it is part of the test conditions.

### Repeat under load, once

After the pitch calibration is done and you have run one height, come back and check the
governor holds its setpoint at **hover collective**, not just flat pitch. This is the
condition that matters and it is the one where saturation shows up.

If the governor droops under load, every row in your data is mislabelled. That is why
`head_rpm_actual` is a required column in the run log and not an optional one.

---

## Record these before the first test run

Put all of this at the top of the run log, or in a file beside it:

- Pitch gauge reference convention (shaft, head, or flat plate)
- Servo microseconds to pitch: slope and intercept, blade A
- Blade A to blade B tracking error, worst case across the range
- Throttle command for each RPM setpoint, at flat pitch
- Governor gain, if you changed it
- Ambient temperature, and pack chemistry and cell count

None of it is interesting on its own. All of it is the difference between a result someone
can reproduce and a spreadsheet nobody can defend.

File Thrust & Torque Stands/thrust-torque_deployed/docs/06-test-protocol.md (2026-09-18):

# 06 - Test Protocol

## What changed, and why

This head is **variable pitch with a governed RPM**. The ESC reads RPM and Austin's software
holds it at a setpoint.

> **Throttle percentage is an RPM setpoint, not a power setting. Thrust comes from
> collective pitch.**

An earlier version of this document walked throttle from 30 to 100 percent at each height.
Under a governor that measures nothing useful: you are commanding a series of RPMs and the
governor is absorbing the difference by changing power on its own terms. That staircase is
gone.

## The three axes

| Axis | Role | Values |
|---|---|---|
| Rotor height | outer loop | z/R = 0.5, 0.75, 1.0, 1.25, 1.5, 2.0 |
| Head RPM | middle loop | 1600, 1700, **1800**, 1900, 2000 |
| Collective pitch | inner loop | staircase in degrees at 0.75R |

At each height you are looking for the **(RPM, pitch) pair that produces 7.5 lbf for the
fewest electrical watts**. That pair is not necessarily the same at every height, which is
one of the more interesting things this rig can tell you.

### Height ladder

Rotor radius is **457 mm**. Measure **rotor plane to floor** with a tape at every step. Do
not trust the cut post length.

| Step | z/R | z (mm) | z (in) | Measured (fill in) | Purpose |
|---|---|---|---|---|---|
| 1 | 0.5 | 229 | 9.0 | | Deep in ground effect |
| 2 | 0.75 | 343 | 13.5 | | |
| 3 | 1.0 | 457 | 18.0 | | |
| 4 | 1.25 | 571 | 22.5 | | |
| 5 | 1.5 | 686 | 27.0 | | |
| 6 | 2.0 | 914 | 36.0 | | **OGE baseline** |

The ladder stops at z/R = 2. The residual Cheeseman-Bennett benefit there is 1.6 percent,
which is below your scatter, so running out to z/R = 3 costs a taller room and buys nothing.

Optional step below z/R = 0.5 if Vermont wants the very-low-hover case. The Cheeseman-Bennett
model is invalid there, which is precisely why it is worth measuring. Expect it to be noisy:
recirculation gets unsteady close to the ground.

**If the radius changes later**, recompute this table as z/R times the new R. Do not reuse
the millimetre column.

### RPM ladder

| Setpoint | Tip speed | BEMT hover W | Measured hover W | Predicted max thrust | Margin |
|---|---|---|---|---|---|
| 1600 | 76.6 m/s | 276 | | 8.6 lbf | 1.14 |
| 1700 | 81.4 m/s | 276 | | 9.7 lbf | 1.29 |
| **1800** | 86.1 m/s | 280 | **446** (flight) | 10.8 lbf | 1.44 |
| 1900 | 90.9 m/s | 286 | | 12.1 lbf | 1.61 |
| 2000 | 95.7 m/s | 294 | | 13.4 lbf | 1.78 |

**1800 is the flying point.** The 446 W column is Austin's flight-test figure per nacelle
and is the number your OGE point at 1800 rpm must land near before any other row means
anything. If it does not, stop and find out why before spending the campaign. The BEMT
column is the model, now known to be about 1.6 low at this point; keep it in the table so
the shape of the RPM trend can still be compared even though the level cannot.

The model says hover power is nearly flat across this range, so **do not expect a dramatic
optimum**. That is a statement about the shape of the curve and may survive the model being
1.6 low in level; the sweep is what tells you. If the measured spread across the RPM ladder is under about 5 percent, that is
the real answer and not a failed experiment. The finding in that case is "RPM is free, so
choose it for thrust margin," which is a perfectly good result to hand Vermont.

Run the full RPM ladder at the **OGE baseline height** and at **one low height**. At the
intermediate heights you can run only the two or three best RPMs from those, unless the
optimum is moving with height, in which case run them all.

### Collective staircase

At each height and each RPM, step collective in **degrees at 0.75R**, using the calibration
from doc 05a. Suggested steps, adjusted to bracket 7.5 lbf with points either side:

| RPM | Suggested collective steps at 0.75R (deg) |
|---|---|
| 1600 | 6, 9, 11, 13, 15, 17 |
| 1700 | 5, 8, 10, 12, 14, 16 |
| 1800 | 4, 7, 9, 11, 13, 15 |
| 1900 | 4, 6, 8, 10, 12, 14 |
| 2000 | 3, 6, 8, 10, 12, 14 |

Predicted hover pitch is 16.1 degrees at 1600 rpm falling to 10.3 at 2000. You need at least
two measured points **below** and one **above** 7.5 lbf at each RPM so the interpolation is
bracketed rather than extrapolated.

Hold each step **five seconds** and record the **settled** value, not the peak. Run the
staircase up and then back down, so you can see hysteresis and thermal drift.

## Before any run: two calibrations you cannot skip

These are done once, on the bench, and are documented in **doc 05a**.

1. **Servo microseconds to blade pitch at 0.75R**, on both blades, with a tracking check.
2. **Throttle command to governed RPM**, at flat pitch.

Without the first you have no inner axis, only servo counts. Without the second you cannot
confirm the governor is doing what you asked. Do them in that order.

The load cell calibration in doc 05 must also be complete, **in both directions**, with
continuity through zero verified. This rig passes through zero net load at around 4.8 lbf of
thrust and it does so in the middle of every sweep.

## Per-run sequence

1. Set the post section. **Measure and record the actual rotor height.**
2. Bring the rig to full running configuration and power it for **two minutes** so it
   settles thermally before you tare against it.
3. **Tare** with the motor off, nacelle mounted, rig completely settled. Send `t`. Record
   the raw offset. The tare is what removes the nacelle's dead-weight compression, so every
   reading after it is pure thrust.
3a. **Confirm the sign before the first run of the day.** Send `d` and check `sign : -1`,
   then lift the nacelle mount by hand and confirm `r` goes **positive**. If it goes
   negative, someone recalibrated and did not send `f`. Fix it now; a whole campaign logged
   with the sign backwards looks perfectly plausible until you plot it.
4. Watch the zero for **30 seconds**. If it walks, stop and find out why. Do not proceed.
5. Send `s` to start streaming.
6. Spool up to the target governed RPM **at minimum collective**.
7. Confirm the governor has settled at the setpoint. Record the **flat-pitch point**: thrust
   should be near zero and the watts you see there are drivetrain and profile drag. This
   point is useful and free.
8. Walk the collective staircase up, five seconds per step. At each step log thrust, volts,
   amps, and the **actual** RPM, not just the commanded one.
9. Walk it back down through the same steps.
10. Return to minimum collective, spool down.
11. Motor off, rig settled. **Tare again** and confirm the zero returns.

Then repeat from step 6 for the next RPM setpoint. Height is the outer loop, so you only
move the post once per height.

## The same sequence in `tools/live.py`

The steps above are written as raw serial commands, which is what you send from the Arduino
Serial Monitor or `screen`. In the browser dashboard they map to controls, and three of them
get easier rather than just different.

| Step | In `live.py` |
|---|---|
| 3, tare | **Tare** button |
| 3a, confirm the sign | The settings line under the live number shows `sign` continuously. Lift the mount and watch the big number go positive. No `d` needed |
| 4, watch the zero for 30 s | The strip chart and the **30 s** statistics line. Read the standard deviation and the peak-to-peak band instead of eyeballing a scrolling column of text |
| 5, 10, start and stop streaming | **Stream** button, lit while active |
| 8, log each plateau | **Capture point**. Fill in height, RPM, collective, throttle, volts, amps. It averages the last 5 seconds and writes the `run-log.csv` row, computing `z_over_R` for you |
| 11, tare again | **Tare**, then compare against the offset you recorded at step 3 |

Three things worth knowing that change how you run the sequence:

**Step 4 gets a real criterion.** "If it walks, stop" is a judgement call when you are
reading numbers scroll past. The statistics panel gives you a number: note the 30 s standard
deviation with the rig cold and settled, and treat any later drift well outside that band as
the zero walking.

**Step 8 stops being transcription.** You are averaging five seconds automatically rather
than picking a plateau value by eye, and the row lands in the CSV in the schema `reduce.py`
expects. The captured points also appear on the power chart as you go, so you can see the
campaign taking shape against the BEMT prediction and notice a bad point while the rig is
still at that height.

**Everything is logged regardless.** `logs/stream-*.csv` records every sample that arrives,
whether or not you captured a point. If a run looks wrong afterwards you still have the raw
trace of it.

What does not change: the tare discipline, the sign check, the flat-pitch point at step 7,
walking the staircase both up and down, and discarding the run if the second tare has
wandered. None of those are about the readout tool.

Step 11 is the one people skip. If the second tare has wandered, something shifted mid-test
and the run is not trustworthy. Throw it out and find out what moved. Ten seconds of work
that catches the failures which otherwise look like real data.

## Two governor failure modes to watch

**Saturation.** If the governor runs out of authority it will droop below the setpoint while
still reporting that it is trying. You are then silently off the grid: your "1800 rpm" row
is actually 1650. This is why step 8 logs actual RPM. If actual departs from commanded by
more than about 2 percent, the row is not what its label says.

**Hunting.** On a rigid stand there is no airframe mass to damp the governor loop, so it can
oscillate in a way it never would in flight. It shows as a periodic wobble in both thrust
and current. This is a **gain problem, not a load cell problem**, and chasing it in the
mechanical build will waste your afternoon. If it appears, back the governor gain off and
note it in the log.

## What to record per plateau

Fill in `data/run-log-template.csv`.

| Field | Source | Note |
|---|---|---|
| height_mm | tape measure | measured, not nominal |
| z_over_R | computed | height divided by 457 |
| head_rpm_cmd | your setpoint | what you asked for |
| head_rpm_actual | tach or telemetry | **what you got.** These differ. |
| collective_deg | doc 05a calibration | degrees at 0.75R |
| servo_us | servo command | the raw number, for traceability |
| throttle_pct | transmitter | now only a governor setpoint record |
| thrust_lbf | load cell, settled value | |
| volts | inline watt meter | **under load**, not resting voltage |
| amps | inline watt meter | not ESC telemetry |
| pack_soc | your note | state of charge at start of run |
| notes | you | vibration, sound changes, drift, anything odd |

`collective_deg` and `head_rpm_actual` are the two new columns that make the reduction
possible. Without them the run is not analysable.

## Safety note specific to this protocol

You will be spending time at **high collective and high RPM** looking for the thrust
ceiling. At 2000 rpm this rotor can produce over 13 lbf on a stand that weighs a few pounds.
Read doc 09 before the first spin, and hold the rig down properly.

**Current.** Hover is now 21 A per nacelle at 21 V, not the 13 A the earlier documents
assumed, and the thrust ceiling will pull well past that. Before the first full-power run
confirm the ESC rating, the pack lead and loom gauge, every connector in the power path,
and that the watt meter reads past 40 A without clipping. A Micro-Fit 3.0 circuit is good
for about 8.5 A; if pack or phase current runs through one, it needs several circuits
paralleled and the derating chart, not one pin.

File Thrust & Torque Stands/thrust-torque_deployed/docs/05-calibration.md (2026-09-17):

# 05 - Calibration

The cell is only as honest as what you calibrated it against. Do this before any data goes
to Vermont.

## What calibration actually is

The HX711 returns raw counts. Calibration establishes one number, `calFactor`, in **counts
per pound of force**. The sketch stores it in EEPROM so it survives power cycles.

Tare and calibration are different things:

- **Tare** sets the zero point. It changes every run.
- **Calibration** sets the slope. It changes only if you change the mechanical setup.

## Which way the cell is loaded, and why `f` is mandatory

The stack is: **legs, post, S-beam load cell bolted to the top of the post, nacelle bolted
on top of the cell.** Everything above the cell's upper face is what gets measured.

The cell is **bolted through studs and jam nuts at both ends**. It is not resting on
anything and nothing is resting loose on it. That is what makes the rig read **tension as
well as compression**, which this measurement requires: nacelle dead weight pushes **down**
on the cell, and rotor thrust pulls **up** on it, and the cell passes continuously through
zero between them.

Consequences that run through the whole procedure:

- **You tare with the nacelle mounted and the motor off.** That sets zero at the dead-weight
  compression point, so every later reading is pure thrust.
- **Calibration is done in compression**, by stacking known weight on the nacelle mount.
  There is nowhere to hang a weight for a tension pull, and the post prevents inverting the
  stand.
- **`c` always makes the calibration direction positive.** So calibrating in compression
  makes *downward* positive, and thrust pulling up would log as negative.
- **Therefore `f` is required after every calibration.** Not "if it reads negative". Always.
  It is the step that makes thrust positive on this geometry.

## Procedure

Assemble the stand fully, **prop removed**, in the same orientation you will test in.
Calibrating in a different orientation gives you a different answer.

1. Connect USB, open the serial monitor at **115200 baud**, set line ending to Newline.
2. Send `d`. Confirm `HX711 ready : yes`. If not, check DT/SCK and 5V/GND.
3. Let it sit powered for two minutes. Strain gauges drift with temperature and you want
   the electronics in a settled thermal state.
4. Send `t` to tare. Everything settled, nothing touching the rig.
5. Send `r` a few times. Should read within a few hundredths of zero. If it wanders, you
   have a mechanical or noise problem. Fix it before continuing.
6. Hang or apply a **known weight** at the nacelle mount, along the post axis.
7. Send `c 5.0` (substitute your actual weight in lbf). The sketch computes and saves
   `calFactor`, and flips the sign automatically if the signal came out negative.
8. Send `d`. Confirm `calFactor` is no longer `1.0000`.
9. Remove the weight. Reading should return to near zero.
10. Apply a **second, different** known weight and send `r`. It should read close to that
    weight. This is the check that the factor is real rather than merely stored.

### Choosing the weight

Use something in the **10 to 15 lbf** range if you can. The cell is 20 kg (44.1 lbf full
scale, 150% safe overload), so 15 lbf is about a third of range and carries no risk, and it
sits just above your expected peak thrust rather than being extrapolated up to it. A 3 lb
weight will produce a working factor, but the noise band is a larger fraction of it.

**Gravity is the only accurate force reference on the bench.** Spring gauges, luggage
scales and fish scales are all less accurate than the cell you are calibrating, so do not
pull by hand against one. On this rig the weight is **stacked on the nacelle mount**, not
hung: the cell is under the nacelle, so there is nothing below it to hang from.

Water is a good cheap standard: one US gallon is **8.345 lb**, it is self-levelling so the
centre of mass behaves, and adding it a gallon at a time gives you a multi-point linearity
check for free instead of a single point. Weigh the empty container and include it.

**Do not try to calibrate in tension.** The post is in the way, so the stand cannot be
inverted, and converting a hanging weight into an upward pull needs a pulley. A plain
bushing pulley eats two or three percent in friction, which reads as a systematically light
calibration and leaves no trace in the data. Calibrate in compression and flip the sign;
the next section explains why that is sound rather than a compromise.

## Two-point plus linearity

The above is a two-point calibration: zero and one known load. Now verify the middle.

| Applied | Made from | Expected | Measured | Error |
|---|---|---|---|---|
| 0 lb | - | 0.00 | | |
| 2 lb | 2 | 2.00 | | |
| 5 lb | 5 | 5.00 | | |
| 7 lb | 2 + 5 | 7.00 | | |
| 10 lb | 10 | 10.00 | | |
| 12 lb | 2 + 10 | 12.00 | | |
| 0 lb | - | 0.00 | | |

Every row is buildable from the 2, 5 and 10 lb weights in the bill of materials. The 12 lb
row is worth doing because it brackets your expected peak thrust rather than interpolating
to it.

Fill this in. Two things to look for:

- **Linearity.** Errors should be small and not systematically curved. The cell itself is
  good to about 0.013 lb, so anything over 0.1 lb is coming from your mounting or your
  reference weights, not the sensor. Over 0.25 lb wants investigating properly.
- **Return to zero.** The last row matters as much as the others. If it does not come back,
  something is slipping, creeping, or the cell was overloaded.

## Direction check

Push down on the nacelle mount by hand. Note the sign. Now **lift** it. The sign must
reverse. If it does not, the cell is not seeing axial load properly, or one of the two studs
is not carrying tension, and something in the stack is shunting force around the cell.

That both directions read at all is the point of bolting the cell at both ends. A cell that
merely had weight resting on it would read compression and then unload to zero, and you
would lose every reading above dead weight, which is most of the useful range.

With the calibration done and `f` sent, **thrust must read positive.** Confirm it by hand
before the first spin.

### `f` is required, it is not a fallback

`c` sets the sign from whichever way the signal moved. On this rig you calibrate in
compression, because that is the only direction you can apply a known force. So `c` makes
**down** positive, and thrust pulling **up** would log negative for the whole campaign.

Send `f` once after every `c`, then confirm: `d` shows `sign : -1`, and lifting the mount by
hand gives a positive `r`.

**Do not use the green/white wire swap instead.** It reaches the same place, but then a
future recalibration plus `f` would flip you back the wrong way. Keep the wiring as
documented and let `f` carry the sign.

**Order matters, and this is easy to get wrong.** `c` re-derives the sign every time it
runs, so any recalibration silently undoes a previous `f`. The sequence is always:

1. `t` with the rig settled
2. apply the known weight, `c <lbf>`
3. `f`
4. `d`, confirm the sign
5. lift by hand, `r`, confirm positive

Do `f` last, every time.

Calibrating in compression is not a compromise. An S-beam is a symmetric structure and this
cell's linearity is specified at 0.03% of full scale, so its counts per lbf are the same in
both directions to well inside anything you can measure here. And as the next section
explains, this rig crosses zero mid-sweep regardless, so you are using both sides whichever
way you calibrate.

## Bidirectional calibration - required on this rig

**Read this before you calibrate.** This stand does not stay in tension.

The nacelle is about 1200 g. With the yoke and adapter plate, roughly **4.5 to 5 lb of dead
weight sits on the cell in compression** before the rotor turns at all. Thrust acts upward,
against that. So as collective comes up, net load on the cell falls, reaches **zero at about
4.8 lbf of thrust**, and then reverses into tension.

That zero crossing is at **64 percent of hover thrust**. It is not at the edge of the range
where you could ignore it. It is in the middle of every sweep you will run.

Three things follow.

### Calibrate in both directions

A single-direction calibration is not enough. Do this:

You cannot apply a known tension force on this geometry without rigging a pulley, and the
stand cannot be inverted because the post is under it. So the working answer is:

1. Calibrate in **compression**, weights stacked on the nacelle mount, then `f`.
2. **Trust the cell, check the joints.** An S-beam is a symmetric structure and this cell is
   specified at 0.03% of full scale for linearity, so its counts per lbf are the same in
   both directions to far inside anything you can resolve here. What is *not* guaranteed
   symmetric is your load path: a joint that takes compression through a shoulder but
   tension through a thread will behave differently either side of zero. That is a
   mechanical fault, and no amount of calibrating finds it. The through-zero sweep below
   does.
3. **Optional, once:** if you want the tension scale factor measured rather than assumed,
   take the cell off the rig and bench-test it on a table with a hook in each end. Use a
   ball-bearing sheave and a truly vertical cord. This validates the cell but not the
   installed load path, so it is the lesser of the two checks.

### Verify continuity through zero

This is the check that matters most and it takes two minutes.

1. Load the cell to roughly **3 lb compression**.
2. Remove load in small increments, perhaps 0.25 lb, reading at each step, **through zero**
   and on into about 2 lb of tension.
3. Plot it or just read down the column.

You are looking for a **step, flat spot, or kink at the crossing**. Any of those is
mechanical clearance in a threaded joint taking up as the load reverses.

> **This is the failure that ruins the deliverable.** A joint with a few thou of clearance
> produces a discontinuity right at 4.8 lbf of thrust, in the middle of your collective
> sweep, and it looks exactly like a real aerodynamic effect. It is smooth, repeatable, and
> entirely fictional. You will be tempted to explain it. Do not; find it and remove it.

If you see it: check the jam nut preload on both studs, confirm nothing in the stack is
relying on a thread to carry tension, and confirm there are no rod ends anywhere in the load
path. Doc 03 covers all three. Re-run this check until the curve through zero is clean.

### Hold-down

At peak thrust the rig sees about **8 lbf of uplift** net of dead weight. Anchor for it.

### Optional ballast, and why it is second choice

Adding about 10 lb of ballast above the cell keeps it in compression across the whole sweep,
which sidesteps the reversal entirely. The cost is that it lowers the fixture's resonant
frequency toward 2/rev, which at 1800 rpm is 60 Hz, and a fixture resonance sitting on a
rotor harmonic will contaminate every reading you take.

Try preload and a clean load path first. Use ballast only if the through-zero check will not
come clean.

## Realistic accuracy of an installed system

The ATO DYLY-102 quotes **0.03 percent of full scale**, which is about 6 g or 0.013 lb on a
20 kg cell. That is the cell alone, on a bench, in a lab, and it is very good.

SparkFun's guide gives a more honest figure for a **built system**: load cell measurements
can be off by roughly plus or minus 5 percent once you account for temperature, creep,
vibration, drift, and assorted electrical and mechanical interference.

Five percent of 7.5 lbf is 0.375 lb. That is worth knowing before you quote a number to
Vermont, and it is the reason the protocol insists on re-taring every run, checking the
zero afterwards, and running the collective staircase both up and down. Those steps are what pull you
back from the 5 percent figure toward the 0.03 percent one.

Put your observed run-to-run repeatability in the delivery note rather than the datasheet
number. It is the honest figure and it is one you actually measured.

## When to recalibrate

- Anything in the stack was unbolted and rebolted
- The cell was overloaded, dropped, or the stud bottomed out
- The ambient temperature changed a lot between sessions
- Readings look implausible

Tare, by contrast, happens **every single run**. See doc 06.

## Common failures

| Symptom | Likely cause |
|---|---|
| Reads zero always, `HX711 ready: NO` | DT/SCK swapped, or no 5V/GND |
| Wildly noisy with motor off | Bad solder on the cell wires, or shield grounded at both ends |
| Clean with motor off, hash under power | Cable routing near motor phase leads. See doc 04. |
| Signal too small during `c` | Weight not actually applied along the axis, or load shunted by a brace |
| Zero drifts steadily | Thermal, if slow. Mechanical creep or a loose joint, if fast. |
| Reading only a fraction of applied weight | Something bridges the cell. Load is bypassing it. |

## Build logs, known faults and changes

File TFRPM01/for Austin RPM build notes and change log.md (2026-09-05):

### 1. Find the drivers list in `default.px4board`

In your editor:

1. Use **Find** (⌘F) and search for:

   * `drivers/`
     or just
   * `"drivers"`

You’re looking for a **list of driver paths** near the bottom of the file. It will look like **one** of these general patterns:

#### Pattern A – JSON-style list

Something like:

```json
"drivers": [
    "drivers/barometer/ms5611",
    "drivers/pwm_out",
    "drivers/tone_alarm",
    ...
]
```

#### Pattern B – CMake-style list (inside a `config`/`cmake` block)

Something like:

```cmake
"config": {
    "nuttx-config": "nuttx_px4_fmu-v6xrt_default",
    "cmake-args": {
        "DRIVERS": [
            "drivers/barometer/ms5611",
            "drivers/pwm_out",
            "drivers/tone_alarm",
            ...
        ],
        "MODULES": [
            ...
        ]
    }
}
```

Or similarly named keys; the key point is there’s a list of `"drivers/..."`.

### 2. Add the PCF8583 RPM driver entry

Once you’ve found that **drivers list**, add this line into it:

```text
"drivers/rpm/pcf8583",
```

Specifically:

* Put it on its own line.
* Put a comma **after** it, except if it’s the very last entry in the list (follow whatever the surrounding lines are doing).
* Place it near other similar drivers (order doesn’t matter for correctness, it’s just for tidiness).

Example for Pattern A:

```json
"drivers": [
    "drivers/barometer/ms5611",
    "drivers/pwm_out",
    "drivers/tone_alarm",
    "drivers/rpm/pcf8583"
]
```

Example inside Pattern B:

```cmake
"cmake-args": {
    "DRIVERS": [
        "drivers/barometer/ms5611",
        "drivers/pwm_out",
        "drivers/rpm/pcf8583",
        "drivers/tone_alarm"
    ],
    "MODULES": [
        ...
    ]
}
```

**Do not** change anything else in the file.

Then **save** the file.

---

### 3. Rebuild with the updated board config

Back in Terminal:

```bash
cd /Users/redfour/Austin_PX4/PX4-Autopilot
make px4_fmu-v6xrt_default
```

Let it go all the way to `Built target px4_package` again.

If it errors, stop and paste the *first* error line to me; that will mean we only need to fix a tiny syntax issue (like a missing comma).

---

### 4. Re-flash this new firmware

You now have a new `.px4` that **should** include `pcf8583`.

From the repo root:

```bash
cd /Users/redfour/Austin_PX4/PX4-Autopilot
make px4_fmu-v6xrt_default upload
```

Or via QGroundControl:

* Vehicle Setup → **Firmware**
* Select **Custom firmware file**
* Pick:
  `/Users/redfour/Austin_PX4/PX4-Autopilot/build/px4_fmu-v6xrt_default/px4_fmu-v6xrt_default.px4`

Let it flash and reboot.

---

### 5. Confirm the driver exists on the board

Once it boots and QGC is connected:

1. Open **MAVLink Console**.

2. Type:

   ```text
   pcf8583 start -X -a 80
   ```

   * If you get something like `pcf8583: started` → we’re in business.
   * If it still says `pcf8583: command not found` → the board file change didn’t compile in, and we’ll adjust the exact spot you edited.

3. Then:

   ```text
   pcf8583 status
   ```

   to see the driver’s status.

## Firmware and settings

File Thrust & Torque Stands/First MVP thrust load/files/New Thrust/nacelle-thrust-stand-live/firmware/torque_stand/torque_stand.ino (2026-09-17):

/*
  torque_stand.ino  -  reaction torque stand, standalone board

  Second Arduino Nano, second HX711, second load cell, own USB port.
  Deliberately NOT sharing the thrust stand's board: separate rigs, separate
  sketches, separate serial ports. See docs/14 for what that costs you in
  time alignment.

  HARDWARE
    Nano (ATmega328P) + Adafruit HX711 #5974 + ATO micro S-type 5 kg,
    M6 male thread both ends.

    HX711 VIN -> Nano 5V
    HX711 GND -> Nano GND
    HX711 DAT -> Nano D2
    HX711 SCK -> Nano D3
    HX711 VIO   unconnected
    RATE switch on L (10 SPS) unless you have measured H and preferred it.

    Cell red    -> E+      (excitation +)
    Cell black  -> E-      (excitation -)
    Cell green  -> A+      (signal +)
    Cell white  -> A-      (signal -)
    Cell shield -> Nano GND, at the Nano end ONLY.

  LIBRARY
    "HX711 Arduino Library" by Bogdan Necula. Not the SparkFun one, not
    the Queuetue one. The API below assumes Bogdan's.

  WHAT IT REPORTS
    Torque directly in newton metres. Calibration is done in torque units
    by hanging a known mass at a caliper-measured radius, so the arm length
    cancels out of the result and never appears in the maths. ARM_R is
    stored only so the sketch can also report the tangential force at the
    cell, which is what you want when you are checking you have not
    overloaded it.

    Reading line:   n,ms,Nm,N,raw
      n    sample counter since boot
      ms   millis() on this board
      Nm   torque, newton metres, signed
      N    tangential force at the load cell pin, newtons
      raw  tare-corrected counts, before calFactor

  SIGN
    The rotor turns one way, so torque is one-signed in service. Set the
    sign once so that running the motor reads POSITIVE, and leave it. As on
    the thrust stand, 'c' always makes the calibration direction positive,
    so if you calibrate by pulling the arm the wrong way you must follow
    with 'f'. Check 'd' before every run.

  WHAT IS NOT STORED
    Tare. setup() re-tares on every boot, and opening the serial port
    resets the board, so never start with the loom dressed differently
    from how it will be in the run, and never start with the rotor turning.

  COMMANDS
    h ?          this help
    t            tare, 32 samples
    r            one reading, 8 samples
    s            toggle streaming
    c <N.m>      calibrate against a known applied torque, 32 samples
    a <mm>       set arm radius, axis to cell pin, for the force column
    f            flip sign, writes EEPROM
    z            raw counts, 32 samples, no tare or scaling
    d            dump settings
    w            force EEPROM write
*/

#include <EEPROM.h>
#include "HX711.h"

// ------------------------------------------------------------------ pins --
const uint8_t PIN_DOUT = 2;
const uint8_t PIN_SCK  = 3;

// --------------------------------------------------------------- sampling --
const uint8_t  READ_AVG  = 8;    // conversions per reported value
const uint8_t  TARE_AVG  = 32;
const uint8_t  CAL_AVG   = 32;
const uint16_t STREAM_MS = 100;  // requested; RATE=L makes the real rate ~1.2 Hz

// ----------------------------------------------------------------- eeprom --
const int EE_MAGIC = 0;   // uint16
const int EE_CAL   = 2;   // float
const int EE_SIGN  = 6;   // int8
const int EE_ARM   = 7;   // float
const uint16_t MAGIC = 0x7451;

// ---------------------------------------------------------------- globals --
HX711 cell;

float  calFactor = 700000.0f;  // counts per N.m, ballpark until calibrated
int8_t signFlag  = 1;
float  armR_mm   = 150.0f;     // axis to cell pin, millimetres

long          tareOffset = 0;
bool          streaming  = false;
unsigned long lastStream = 0;
unsigned long sampleN    = 0;

char    lineBuf[24];
uint8_t lineLen = 0;

// ---------------------------------------------------------------- helpers --
long readRaw(uint8_t n) {
  // Bogdan's read_average returns a long already averaged over n conversions.
  return cell.read_average(n);
}

void doTare(uint8_t n) {
  tareOffset = readRaw(n);
  Serial.print(F("tared, offset "));
  Serial.println(tareOffset);
}

float countsToNm(long corrected) {
  return (float)signFlag * (float)corrected / calFactor;
}

void printReading(uint8_t n) {
  long corrected = readRaw(n) - tareOffset;
  float nm = countsToNm(corrected);
  float force = (armR_mm > 0.1f) ? (nm / (armR_mm / 1000.0f)) : 0.0f;

  sampleN++;
  Serial.print(sampleN);        Serial.print(',');
  Serial.print(millis());       Serial.print(',');
  Serial.print(nm, 4);          Serial.print(',');
  Serial.print(force, 3);       Serial.print(',');
  Serial.println(corrected);
}

void saveSettings() {
  EEPROM.put(EE_MAGIC, MAGIC);
  EEPROM.put(EE_CAL,   calFactor);
  EEPROM.put(EE_SIGN,  signFlag);
  EEPROM.put(EE_ARM,   armR_mm);
  Serial.println(F("settings written"));
}

void loadSettings() {
  uint16_t m = 0;
  EEPROM.get(EE_MAGIC, m);
  if (m != MAGIC) {
    Serial.println(F("no stored settings, using defaults"));
    return;
  }
  EEPROM.get(EE_CAL,  calFactor);
  EEPROM.get(EE_SIGN, signFlag);
  EEPROM.get(EE_ARM,  armR_mm);
  if (!(calFactor > 1.0f)) calFactor = 700000.0f;
  if (signFlag != 1 && signFlag != -1) signFlag = 1;
  if (!(armR_mm > 0.1f)) armR_mm = 150.0f;
}

void dumpSettings() {
  Serial.println(F("--- settings ---"));
  Serial.print(F("calFactor : ")); Serial.print(calFactor, 4);
  Serial.println(F(" counts per N.m"));
  Serial.print(F("sign      : ")); Serial.println((int)signFlag);
  Serial.print(F("armR      : ")); Serial.print(armR_mm, 2);
  Serial.println(F(" mm  (display only, not in the torque maths)"));
  Serial.print(F("tare      : ")); Serial.println(tareOffset);
  Serial.print(F("full scale: "));
  Serial.print(49.03f * (armR_mm / 1000.0f), 3);
  Serial.println(F(" N.m for a 5 kg cell at this radius"));
  Serial.println(F("----------------"));
}

void doCalibrate(float knownNm) {
  if (!(knownNm > 0.0f)) {
    Serial.println(F("ERR: calibration torque must be positive N.m"));
    return;
  }
  long corrected = readRaw(CAL_AVG) - tareOffset;
  long mag = corrected < 0 ? -corrected : corrected;
  if (mag < 1000L) {
    Serial.print(F("ERR: only "));
    Serial.print(mag);
    Serial.println(F(" counts of signal. Is the torque actually applied?"));
    return;
  }
  calFactor = (float)mag / knownNm;
  signFlag  = (corrected >= 0) ? 1 : -1;
  saveSettings();
  Serial.print(F("calFactor "));
  Serial.print(calFactor, 4);
  Serial.println(F(" counts per N.m"));
  Serial.println(F("NOTE: 'c' forces the CALIBRATION direction positive."));
  Serial.println(F("      If the motor drives the arm the other way, send 'f' now."));
}

void printHelp() {
  Serial.println(F("torque stand - commands"));
  Serial.println(F("  h ?      help"));
  Serial.println(F("  t        tare (32)"));
  Serial.println(F("  r        one reading (8)"));
  Serial.println(F("  s        toggle stream"));
  Serial.println(F("  c <N.m>  calibrate against a known applied torque (32)"));
  Serial.println(F("  a <mm>   set arm radius for the force column"));
  Serial.println(F("  f        flip sign (writes EEPROM)"));
  Serial.println(F("  z        raw counts (32)"));
  Serial.println(F("  d        dump settings"));
  Serial.println(F("  w        force EEPROM write"));
  Serial.println(F("line format: n,ms,Nm,N,raw"));
  Serial.println(F("stream is ~1.2 Hz with RATE on L and READ_AVG 8"));
}

// ---------------------------------------------------------------- command --
void handleLine(char *s) {
  while (*s == ' ') s++;
  char c = *s;
  if (c == 0) return;

  switch (c) {
    case 'h':
    case '?':
      printHelp();
      break;

    case 't':
      doTare(TARE_AVG);
      break;

    case 'r':
      printReading(READ_AVG);
      break;

    case 's':
      streaming = !streaming;
      if (streaming) Serial.println(F("stream on"));
      else           Serial.println(F("stream off"));
      break;

    case 'z': {
      long v = readRaw(CAL_AVG);
      Serial.print(F("raw "));
      Serial.println(v);
      break;
    }

    case 'd':
      dumpSettings();
      break;

    case 'w':
      saveSettings();
      break;

    case 'f':
      signFlag = (int8_t)(-signFlag);
      saveSettings();
      Serial.print(F("sign now "));
      Serial.println((int)signFlag);
      break;

    case 'c':
      doCalibrate(atof(s + 1));
      break;

    case 'a': {
      float v = atof(s + 1);
      if (v > 0.1f) {
        armR_mm = v;
        saveSettings();
        Serial.print(F("armR "));
        Serial.print(armR_mm, 2);
        Serial.println(F(" mm"));
      } else {
        Serial.println(F("ERR: arm radius must be positive mm"));
      }
      break;
    }

    default:
      Serial.println(F("? try h"));
      break;
  }
}

void pollSerial() {
  while (Serial.available()) {
    char ch = (char)Serial.read();
    if (ch == '\r') continue;
    if (ch == '\n') {
      lineBuf[lineLen] = 0;
      handleLine(lineBuf);
      lineLen = 0;
    } else if (lineLen < sizeof(lineBuf) - 1) {
      lineBuf[lineLen++] = ch;
    }
  }
}

// ------------------------------------------------------------------ setup --
void setup() {
  Serial.begin(115200);
  cell.begin(PIN_DOUT, PIN_SCK);
  cell.set_gain(128);

  loadSettings();

  // Let the bridge settle before taring. The cell has just been powered.
  delay(500);
  doTare(TARE_AVG);

  Serial.println(F("torque stand ready"));
  dumpSettings();
  Serial.println(F("h for help"));
}

void loop() {
  pollSerial();
  if (streaming && (millis() - lastStream >= STREAM_MS)) {
    lastStream = millis();
    printReading(READ_AVG);
  }
}

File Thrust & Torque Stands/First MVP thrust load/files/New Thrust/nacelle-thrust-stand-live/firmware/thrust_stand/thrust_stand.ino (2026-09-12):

/*
 * Nacelle Thrust Stand
 * S-beam load cell + HX711 + Arduino
 *
 * Measures axial thrust on a single VTOL nacelle mounted on an axial post.
 * The cell reads compression at rest (nacelle weight) and tension under thrust
 * (thrust exceeds weight). Both are handled: you tare with the motor off, and
 * every reading after that is change from tare, which is thrust.
 *
 * Requires the bogde HX711 library.
 *   Arduino IDE -> Library Manager -> search "HX711" -> install "HX711 Arduino Library"
 *   by Bogdan Necula. Or: https://github.com/bogde/HX711
 *
 * Serial: 115200 baud. Send 'h' for help.
 *
 * Upload with Arduino IDE 1.8.19, board Arduino Nano, processor plain ATmega328P.
 * NOT IDE 2.x (avrdude 8.0 cannot write this board) and NOT Old Bootloader.
 * See docs/13-arduino-working-config.md.
 *
 * Calibration factor is stored in EEPROM and survives power cycles.
 */

#include <HX711.h>
#include <EEPROM.h>

// ---------------------------------------------------------------- pins

const uint8_t PIN_DOUT = 2;   // HX711 DT
const uint8_t PIN_SCK  = 3;   // HX711 SCK

// ---------------------------------------------------------------- config

const uint32_t SERIAL_BAUD   = 115200;
const uint16_t STREAM_MS     = 100;   // asks for 10 Hz; the real rate is set by the
                                      // HX711 RATE switch and READ_AVG below.
                                      // RATE=L (10 SPS) x READ_AVG 8 => ~1.2 Hz.
                                      // RATE=H (80 SPS) x READ_AVG 8 => 10 Hz.
const uint8_t  READ_AVG      = 8;     // HX711 samples per reported value
const uint8_t  CAL_AVG       = 32;    // samples used during calibration
const float    LBF_TO_N      = 4.4482216f;

// ---------------------------------------------------------------- EEPROM

const int      EE_ADDR_MAGIC = 0;
const int      EE_ADDR_CAL   = 4;
const int      EE_ADDR_SIGN  = 8;
const uint32_t EE_MAGIC      = 0x54485231UL;   // "THR1"

// ---------------------------------------------------------------- state

HX711    scale;
float    calFactor  = 1.0f;    // HX711 counts per lbf
int8_t   signFlip   = 1;       // +1 or -1
bool     streaming  = false;
uint32_t lastStream = 0;
uint32_t sampleNum  = 0;

char     cmdBuf[24];
uint8_t  cmdLen = 0;

// ---------------------------------------------------------------- EEPROM helpers

void saveSettings() {
  uint32_t magic = EE_MAGIC;
  EEPROM.put(EE_ADDR_MAGIC, magic);
  EEPROM.put(EE_ADDR_CAL, calFactor);
  EEPROM.put(EE_ADDR_SIGN, signFlip);
}

bool loadSettings() {
  uint32_t magic = 0;
  EEPROM.get(EE_ADDR_MAGIC, magic);
  if (magic != EE_MAGIC) return false;
  EEPROM.get(EE_ADDR_CAL, calFactor);
  EEPROM.get(EE_ADDR_SIGN, signFlip);
  if (!(calFactor > 0.0f) || isnan(calFactor)) { calFactor = 1.0f; return false; }
  if (signFlip != 1 && signFlip != -1) signFlip = 1;
  return true;
}

// ---------------------------------------------------------------- measurement

// Thrust in lbf. get_units() returns (raw - offset) / calFactor, so with the
// offset set by tare() this is change-from-tare expressed in pounds.
float readLbf(uint8_t n) {
  return signFlip * scale.get_units(n);
}

void printHeader() {
  Serial.println(F("# n,ms,lbf,N,raw"));
}

void printReading(uint8_t n) {
  float lbf = readLbf(n);
  long  raw = scale.read_average(2);
  Serial.print(sampleNum++);        Serial.print(',');
  Serial.print(millis());           Serial.print(',');
  Serial.print(lbf, 4);             Serial.print(',');
  Serial.print(lbf * LBF_TO_N, 3);  Serial.print(',');
  Serial.println(raw);
}

// ---------------------------------------------------------------- commands

void printHelp() {
  Serial.println();
  Serial.println(F("=== Nacelle Thrust Stand ==="));
  Serial.println(F("  h            this help"));
  Serial.println(F("  t            TARE. motor off, rig settled. do this every run."));
  Serial.println(F("  r            single reading"));
  Serial.println(F("  s            start / stop streaming (RATE=L gives ~1.2 Hz, H gives 10)"));
  Serial.println(F("  c <lbf>      calibrate: tare first, hang known weight, then e.g. 'c 5.0'"));
  Serial.println(F("  f            flip sign. REQUIRED after every 'c' on this rig."));
  Serial.println(F("  z            raw counts, no scaling. for diagnostics."));
  Serial.println(F("  d            dump settings"));
  Serial.println(F("  w            write settings to EEPROM"));
  Serial.println();
  Serial.println(F("Procedure per run: 't' with motor off, 's' to stream, run the"));
  Serial.println(F("collective staircase at a governed RPM, 's' to stop, then 't'"));
  Serial.println(F("again and check zero."));
  Serial.println(F("If the second tare has wandered, discard the run."));
  Serial.println();
}

void dumpSettings() {
  Serial.println();
  Serial.print(F("  calFactor (counts/lbf) : ")); Serial.println(calFactor, 4);
  Serial.print(F("  sign                   : ")); Serial.println((int)signFlip);
  Serial.print(F("  tare offset (counts)   : ")); Serial.println(scale.get_offset());
  Serial.print(F("  HX711 ready            : ")); Serial.println(scale.is_ready() ? F("yes") : F("NO"));
  Serial.println();
}

void doTare() {
  Serial.println(F("# taring, hold still..."));
  scale.tare(CAL_AVG);
  Serial.print(F("# tare offset = "));
  Serial.println(scale.get_offset());
  Serial.println(F("# zeroed. readings are now change from tare."));
}

void doCalibrate(float knownLbf) {
  if (!(knownLbf > 0.0f)) {
    Serial.println(F("! calibration weight must be positive, e.g. 'c 5.0'"));
    return;
  }
  Serial.print(F("# calibrating against "));
  Serial.print(knownLbf, 3);
  Serial.println(F(" lbf. hold still..."));

  // get_value() is raw minus tare offset, unscaled.
  float counts = scale.get_value(CAL_AVG);

  if (fabs(counts) < 1000.0f) {
    Serial.println(F("! signal too small. is the weight applied? is the cell wired?"));
    return;
  }

  if (counts < 0) {
    signFlip = -1;
    counts = -counts;
    Serial.println(F("# negative signal, sign flipped automatically"));
  } else {
    signFlip = 1;
  }

  calFactor = counts / knownLbf;
  scale.set_scale(calFactor);
  saveSettings();

  Serial.print(F("# calFactor = "));
  Serial.print(calFactor, 4);
  Serial.println(F(" counts/lbf, saved to EEPROM"));
  Serial.print(F("# check: reading now "));
  Serial.print(readLbf(CAL_AVG), 4);
  Serial.println(F(" lbf"));
}
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
